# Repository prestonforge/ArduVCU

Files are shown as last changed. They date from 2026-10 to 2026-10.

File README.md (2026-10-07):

# ArduVCU — low-cost racing telemetry for Greenpower F24

**A £55 open-source vehicle control unit that gives Greenpower F24 drivers live battery telemetry and predictive pacing — built because commercial systems cost £100+ and junior teams drive blind.**

Awarded the **Gold CREST Award** by the British Science Association (April 2026) — 78 logged project hours.

## The problem

Greenpower F24 teams race on a fixed 24V lead-acid battery. The driver has no instrumentation: they can't see how fast the battery is actually draining, so they can't pace. The result is the "Feedback Gap" — batteries die before the finish line, or the car crawls home with charge to spare. Commercial telemetry (e.g. eChook Nano) costs £100+ and needs a smartphone, which puts it out of reach for most school teams.

## How it works

An ESP32 reads the traction battery through isolated sensing and turns raw current/voltage into **live minutes-remaining**, using Peukert's Law — because lead-acid batteries deliver *less* capacity the harder you pull current:

- **Predictive runtime** — Peukert estimation implemented from scratch in C++, no libraries
- **O(1) signal filtering** — a circular-buffer moving average (10 samples, modulo wrap-around) that tames motor EMI without re-summing on every loop
- **Hysteresis safety state machine** — "Limp Mode" at 21.0 V deep sag; full power only returns once voltage recovers by a 1.5 V dead-band. No relay chatter, no welded contactors
- **Isolated architecture** — 24 V traction power stepped down via a 100k/10k divider; current measured by a galvanically isolated ACS712 Hall-effect sensor (up to 30 A)
- **12-bit ADC** — 4,096 steps vs the 1,024 of typical 10-bit microcontrollers, enough to catch micro-fluctuations in current draw
- **Digital twin — real and open-source** — the 0.05 V/min pacing budget comes from a first-order lead-acid discharge model (Peukert's Law + internal-resistance sag). Two working, auditable versions ship with this repo: an interactive browser twin → [prestonforge.github.io/digital-twin.html](https://prestonforge.github.io/digital-twin.html), and a full Excel model with live formulas in `/docs`
- **Fusion 360 enclosure** — ABS (not PLA: it warps at 60 °C next to a hot motor), brass threaded inserts, U-shaped cable slots for track vibration

## A documented pivot

The original design drove an I2C OLED cockpit display. It never initialised. After a systematic debug (I2C scanner, physical-layer checks, address verification) the project pivoted to **headless serial telemetry** — streaming at 2 Hz to a ground-station laptop. Better outcome: full data for aerodynamic tuning instead of a 0.96-inch driver display.

## Bill of materials (≈£55)
   Item | Purpose |
 |---|---|
 | ESP32 DevKit (12-bit ADC) | Core MCU + telemetry |
 | ACS712 Hall-effect sensor (30 A) | Isolated current measurement |
 | 100k/10k resistor divider | 24 V → logic-level voltage sense |
 | Relay + contactor interface | Motor safety cut-off |
 | Enclosure (ABS, FDM-printed) | Vibration-resistant housing |

Commercial equivalent: ~£100+ plus an Android phone.

## Status

- [x] Breadboard prototype — working, logged 78 hrs, Gold CREST assessed
- [ ] Custom PCB port (from breadboard)
- [ ] Race-day installation + live pacing validation
- [ ] Full open-source toolchain release for school teams

## License

MIT — see LICENSE. Built for school STEM racing teams; use it, improve it, pass it on.

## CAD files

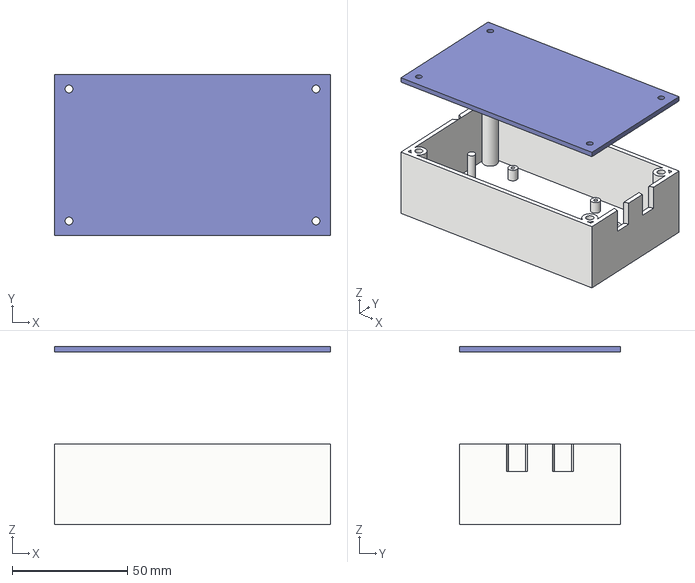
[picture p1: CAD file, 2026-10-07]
docs/ArduVCU+Enclosure.stp
120.0 x 70.0 x 77.5 mm

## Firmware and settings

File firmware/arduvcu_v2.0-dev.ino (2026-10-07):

/* =====================================================
   ArduVCU Firmware v2.0-dev
   Refactor of the CREST Gold Release v1.3 (April 2026)
   Greenpower F24 — predictive telemetry & battery management

   STATUS: development refactor, hardware validation pending.
   v1.3 remains the assessed Gold Release until this is
   bench-tested against v1.3 behaviour.

   Changes vs v1.3:
     1. analogReadMilliVolts() — eFuse-calibrated ADC readings
     2. O(1) circular-buffer filtering on BOTH voltage and current
     3. Non-blocking 50 Hz sampling, 2 Hz telemetry (was 2 Hz delay())
     4. Live discharge-gradient telemetry vs the 0.05 V/min
        pacing target from the Excel digital twin
     5. NTC thermal monitoring with 90 C emergency cutoff
        (per the project risk assessment)
     6. Minimum 2 s relay dwell — contactor protection
     7. Fail-safe boot: relay OFF until first healthy reading
     8. Safety commands retried every pass — a dwell-blocked
        trip can never be silently lost; thermal trip needs
        2 consecutive 1 Hz readings (no noise-spike shutdowns)
   ===================================================== */

#include <math.h>

// ---------- PIN MAP (unchanged from v1.3) ----------
const int VOLT_PIN  = 34;   // 100k/10k divider (11:1), ADC1, input-only
const int AMP_PIN   = 35;   // ACS712-30A output,     ADC1, input-only
const int NTC_PIN   = 32;   // motor NTC 10k (B3950), ADC1, input-only
const int RELAY_PIN = 25;   // motor safety contactor

// ---------- SIGNAL FILTERING (O(1) circular buffers) ----------
const int   NUM_SAMPLES  = 10;     // per-channel ring depth
const int   SAMPLE_MS     = 20;    // 50 Hz filter update
const float NOISE_GATE_A  = 0.30f; // ACS712 quiescent noise band

// ---------- BATTERY MODEL (Greenpower regulations) ----------
const float CAPACITY_AH   = 20.0f;
const float PEUKERT_K     = 1.15f;  // lead-acid
const float DIVIDER_RATIO = 11.0f;   // (100k + 10k) / 10k

// ---------- PACING (Excel digital-twin target) ----------
const float TARGET_V_PER_MIN = 0.05f;
const int   SLOPE_WINDOW_S   = 60;   // rolling gradient window

// ---------- HYSTERESIS SAFETY (v1.3 values kept) ----------
const float CUTOFF_V      = 21.0f;   // deep sag -> Limp Mode
const float HYST_BUFFER_V = 1.5f;    // recovery dead-band
const unsigned long MIN_RELAY_DWELL_MS = 2000; // contactor protection

// ---------- THERMAL (per project risk assessment) ----------
const float NTC_PULLUP_OHMS    = 10000.0f;
const float NTC_R0_OHMS        = 10000.0f;  // at 25 C
const float NTC_BETA           = 3950.0f;
const float THERMAL_CUTOFF_C   = 90.0f;
const float THERMAL_REARM_C    = 70.0f;      // thermal dead-band

// ---------- TELEMETRY ----------
const unsigned long TELEMETRY_MS = 500;      // 2 Hz, as v1.3

// ---------- FILTER STATE ----------
long  voltTotal = 0, ampTotal = 0;
int   voltRing[NUM_SAMPLES], ampRing[NUM_SAMPLES];
int   ringIndex = 0;
float smoothedVolt = 0.0f, smoothedAmps = 0.0f;

// ---------- SAFETY STATE ----------
bool  limpMode    = false;
bool  thermalTrip = false;
bool  relayState  = false;       // software mirror of the contactor pin
bool  tempValid   = false;       // refreshed at the 1 Hz tick
int   hotCount    = 0;           // consecutive 1 Hz overheat readings
unsigned long lastRelayChange = 0;
float tempC = NAN;               // shared global, refreshed at 1 Hz (FAULT till then)

// ---------- SLOPE STATE (1 Hz voltage history) ----------
const int SLOPE_N = SLOPE_WINDOW_S + 1;
float slopeRing[SLOPE_N];
int   slopeIndex = 0;
int   slopeFilled = 0;           // counts up to SLOPE_N, then gradient is valid
float dischargeVPerMin = 0.0f;

unsigned long lastSample = 0, lastSlope = 0, lastTelemetry = 0;

// ---------------- HELPERS ----------------
float readTempC() {
  // NTC high side to 3V3, fixed 10k low side to GND
  float mv   = analogReadMilliVolts(NTC_PIN);
  if (mv <= 1.0f || mv >= 3299.0f) return NAN;  // wiring fault
  float rNtc = NTC_PULLUP_OHMS * (3300.0f - mv) / mv;
  float tK   = 1.0f / (1.0f / 298.15f + logf(rNtc / NTC_R0_OHMS) / NTC_BETA);
  return tK - 273.15f;
}

void updateFilters() {
  // O(1) circular buffers: subtract oldest, add newest, modulo wrap
  voltTotal -= voltRing[ringIndex];
  ampTotal  -= ampRing[ringIndex];
  voltRing[ringIndex] = analogReadMilliVolts(VOLT_PIN);
  ampRing[ringIndex]  = analogReadMilliVolts(AMP_PIN);
  voltTotal += voltRing[ringIndex];
  ampTotal  += ampRing[ringIndex];
  ringIndex = (ringIndex + 1) % NUM_SAMPLES;

  smoothedVolt = (float)voltTotal / NUM_SAMPLES * DIVIDER_RATIO / 1000.0f;
  float amps = ((float)ampTotal / NUM_SAMPLES - 1650.0f) / 66.0f;
  smoothedAmps = (fabs(amps) < NOISE_GATE_A) ? 0.0f : amps;
}

bool relayAllowed() {
  // contactor dwell: no relay transition inside the minimum window
  return (millis() - lastRelayChange) >= MIN_RELAY_DWELL_MS;
}

void setRelay(bool on) {
  if (on == relayState || !relayAllowed()) return;
  digitalWrite(RELAY_PIN, on ? HIGH : LOW);
  relayState = on;
  lastRelayChange = millis();
}

void safetyStateMachine() {
  // --- thermal trip (hotCount is incremented only at the 1 Hz tick) ---
  if (!thermalTrip && hotCount >= 2) {         // 2 s sustained overheat, not a spike
    thermalTrip = true;
    limpMode = true;
  }
  if (thermalTrip && tempValid && tempC < THERMAL_REARM_C) {
    thermalTrip = false;                       // re-arm only below the dead-band
  }

  if (thermalTrip) { setRelay(false); return; }  // retried EVERY pass: can't be lost

  // --- voltage hysteresis (v1.3 logic, dwell-protected) ---
  if (smoothedVolt <= CUTOFF_V) {
    limpMode = true;                        // latch the flag...
    setRelay(false);                        // ...and command OFF every pass — a
                                             // dwell-blocked call is retried, never lost
  } else if (limpMode && smoothedVolt >= (CUTOFF_V + HYST_BUFFER_V)) {
    limpMode = false;
    setRelay(true);                         // recovered past the 1.5 V dead-band
  } else if (!limpMode) {
    setRelay(true);                         // NOMINAL: engage after healthy boot
  }
}

void updateSlope() {
  slopeRing[slopeIndex] = smoothedVolt;
  slopeIndex = (slopeIndex + 1) % SLOPE_N;
  if (slopeFilled < SLOPE_N) { slopeFilled++; return; }  // first 60 s = warm-up
  float oldest = slopeRing[slopeIndex];          // value 60 s ago
  dischargeVPerMin = (oldest - smoothedVolt);   // +ve = discharging
}

void telemetry() {
  Serial.print(F("BATT: "));
  Serial.print(smoothedVolt, 2);
  Serial.print(F("V | LOAD: "));
  Serial.print(fabs(smoothedAmps), 2);
  Serial.print(F("A"));

  if (fabs(smoothedAmps) > NOISE_GATE_A) {
    // Peukert: effective runtime shrinks as current rises
    float hoursRem = CAPACITY_AH / powf(fabs(smoothedAmps), PEUKERT_K);
    Serial.print(F(" | EST: "));
    Serial.print(hoursRem, 2);
    Serial.print(F("h"));
  } else {
    Serial.print(F(" | EST: IDLE (no load)"));
  }

  Serial.print(F(" | SLOPE: "));
  if (slopeFilled < SLOPE_N) {
    Serial.print(F("WARMUP"));                  // don't fake a 0.000 "on pace" reading
  } else {
    Serial.print(dischargeVPerMin, 3);
    Serial.print(F("V/min (target "));
    Serial.print(TARGET_V_PER_MIN, 2);
    Serial.print(F(")"));
  }

  Serial.print(F(" | TEMP: "));
  if (tempC != tempC) { Serial.print(F("FAULT")); }   // NAN check
  else                { Serial.print(tempC, 1); Serial.print(F("C")); }

  Serial.print(F(" | STATUS: "));
  if (thermalTrip)     Serial.println(F("THERMAL_SHUTDOWN"));
  else if (limpMode)   Serial.println(F("LIMP_MODE_ACTIVE"));
  else                  Serial.println(F("NOMINAL"));
}

// ---------------- SETUP / LOOP ----------------
void setup() {
  Serial.begin(115200);
  pinMode(RELAY_PIN, OUTPUT);
  digitalWrite(RELAY_PIN, LOW);          // FAIL-SAFE: boot OFF

  // Pre-fill both buffers with LIVE data (prevents false trip on boot)
  for (int i = 0; i < NUM_SAMPLES; i++) {
    voltRing[i] = analogReadMilliVolts(VOLT_PIN);
    ampRing[i]  = analogReadMilliVolts(AMP_PIN);
    voltTotal += voltRing[i];
    ampTotal  += ampRing[i];
    delay(10);                            // ADC mux settle, as v1.3
  }
  for (int i = 0; i < SLOPE_N; i++) slopeRing[i] = 0.0f;

  updateFilters();
  Serial.println(F("--- ArduVCU v2.0-dev SYSTEMS ONLINE ---"));
  Serial.println(F("Waiting for telemetry stream..."));
  // Relay engages only after the first healthy state-machine pass
}

void loop() {
  unsigned long now = millis();

  if (now - lastSample >= (unsigned)SAMPLE_MS) {     // 50 Hz
    lastSample = now;
    updateFilters();
  }

  if (now - lastSlope >= 1000UL) {                   // 1 Hz gradient + thermal
    lastSlope = now;
    updateSlope();
    tempC = readTempC();                            // 1 Hz: no noise-splice trips
    tempValid = (tempC == tempC);                   // NaN self-check
    if (tempValid && tempC >= THERMAL_CUTOFF_C) hotCount++;   // consecutive readings
    else hotCount = 0;
  }

  safetyStateMachine();

  if (now - lastTelemetry >= TELEMETRY_MS) {         // 2 Hz
    lastTelemetry = now;
    telemetry();
  }
  // No delay(): loop is non-blocking — ready for buttons/display later
}

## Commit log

2026-10-07 docs: add real discharge-model digital twin (Excel)
    [ArduVCU-digital-twin.xlsx]
2026-10-07 Revise Bill of Materials formatting in README
    Updated the Bill of Materials section to improve formatting and clarity. Removed the old table format and replaced it with a new one for better readability.
